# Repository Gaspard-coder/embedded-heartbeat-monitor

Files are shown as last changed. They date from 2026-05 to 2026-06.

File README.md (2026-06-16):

# This repository contains all of the necessary file to make a working heartbeat sensor
- Schematics
- PCB design files
- Embedded code running on MCUs

## Embedded software (`software/hsensor/`)

MicroPython application running on a Raspberry Pi Pico. It samples the
output of the TCRT5000 reflectance sensor (amplified by an op-amp), detects
heartbeats and displays the BPM together with the live waveform on the
0.96" ST7735 LCD.

### Files
- `ST7735.py` — driver for the 0.96" LCD (SPI, same wiring as the demo:
  DC=GP8, CS=GP9, SCK=GP10, MOSI=GP11, RST=GP12, BL=GP13).
- `main.py` — acquisition, heart rate detection and display loop.

### Wiring
- TCRT5000 + op-amp output → **pin 31 (GPIO26 / ADC0)** of the Pico.
- LCD: SPI1 on GP8–GP13 (see above).

### How the algorithm works

1. **Sampling.** `ADC(Pin(26))` is read every 10 ms (≈100 Hz), which is
   well above the highest expected heart-beat frequency (~3 Hz at 180 BPM)
   and matches the cutoff of the analog front-end.

2. **DC removal (high-pass filter).** The raw photoplethysmographic signal
   coming from the TCRT5000 is dominated by a large DC component (ambient
   reflectance of the skin) with a small pulsatile AC component on top. We
   subtract a slowly-tracking baseline computed as an exponential moving
   average:

   ```
   baseline ← (31 · baseline + raw) / 32
   x       ← raw − baseline
   ```

   With `α = 1/32` at 100 Hz, the equivalent cutoff is roughly 0.5 Hz —
   slow enough to leave the heartbeats untouched but fast enough to track
   drift in finger pressure or ambient light.

3. **Peak detection.** A heartbeat appears as a local maximum on the
   filtered signal `x`. For every new sample we check the *previous*
   sample: if it is greater than its two neighbours and above
   `PEAK_THRESHOLD`, it is declared a peak.

4. **Refractory period.** Once a peak has been detected, any new peak
   occurring within 300 ms is ignored. This caps the detected rate at
   200 BPM and avoids counting the dicrotic notch (the small secondary
   bump after each beat) as a separate heartbeat.

5. **BPM computation.** The time difference `dt` between two consecutive
   accepted peaks is pushed into a rolling buffer of the last 5
   intervals. The current heart rate is the average of that buffer:

   ```
   BPM = 60000 / mean(intervals_ms)
   ```

   Averaging over several beats smooths jitter due to noise and gives a
   stable reading on the display. If no peak is seen for more than 2 s
   (i.e. < 30 BPM, almost certainly a lost-contact event) the buffer is
   cleared and the BPM goes back to `--`.

6. **Display.** The LCD is refreshed every 200 ms — redrawing the full
   framebuffer is slow, so we deliberately do not refresh at the sampling
   rate. The top of the screen shows `BPM: XX`, and below it the last
   160 filtered samples are plotted (oldest on the left, newest on the
   right) with a blue zero-line.

### Tuning knobs (top of `main.py`)
- `PEAK_THRESHOLD` — minimum amplitude (in ADC LSB on the filtered signal)
  for a sample to qualify as a peak. Lower it if the analog gain is small,
  raise it if the signal is noisy.
- `BPM_WINDOW` — number of inter-beat intervals averaged.
- `REFRACTORY_MS` / `MAX_INTERVAL_MS` — accepted BPM range (currently
  30–200 BPM).
- `v // 30` in the plotting code — vertical scale of the waveform on the
  LCD.

### Running
Copy `ST7735.py` and `main.py` to the Pico (Thonny, `mpremote cp`, …).
`main.py` runs automatically at boot.

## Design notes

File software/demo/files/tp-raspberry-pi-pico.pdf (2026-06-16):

## Electronique pour les systèmes embarqués

# TP Raspberry PI pico

## 1 Introduction

Dans ce mini-TP, nous nous intéressons à la prise en main de la maquette Raspberry Pi Pico et plus particulièrement de son convertisseur analogique numérique (CAN). La Raspberry Pi Pico est une carte programmable construite autour du microcontrôleur RP2040. La carte intègre un ARM Cortex-M0+ Dual Core à 133 MHz. Elle dispose de 26 broches GPIO dont 3 entrées analogiques connectées à un CAN. La datasheet complète de la carte est disponible sur le lien suivant : https://datasheets.raspberrypi.com/pico/pico-datasheet.pdf.

Question 1.1 Parcourer la rapidement, notamment le chapitre 1 pour connaitre les principales fonctionnalités de la carte.

## 2 Programmation de la carte

La carte Raspberry Pi Pico se programme avec plusieurs langages. Nous vous invitons à utiliser dans le cadre de ce module le langage micropython qui permet de l’interactivité et une facilité d’utilisation. Vous pourrez bien évidemment si vous le souhaitez utiliser d’autres langages supportés par la carte notamment le C/C++. Dans la suite de ce mini-TP, nous utiliserons MicroPython https://www.raspberrypi.com/documentation/microcontrollers/micropython.html.

Pour programmer en MicroPython, il est nécessaire de l’installer sur la carte. Cette opération très simple décrite dans le lien ci-dessus, a été déjà réalisée sur les Raspberry Pi Pico utilisées dans ce TP. Une fois MicroPython installé, il est possible d’utiliser des environnements de développement comme Thonny https://thonny.org/ ou d’interagir avec la carte avec Pyboard.py. C’est un utilitaire qui permet d’interagir avec micropython à partir d’un interpréteur ou d’un code Python tournant sur le poste principal et permet notamment accéder au système de fichier de la carte pico. Nous utiliserons cette deuxième solution dans le cadre de ce mini-TP. Cependant l’utilisation de Thonny a également des intérêts en termes d’interactivité. N’hésitez pas à l’installer et l’utiliser pour le projet fil-rouge du module.
Sachez qu’il est possible d’avoir différents codes python sur la carte mais le code qui s’exécutera lors du démarrage est le code main.py qui bien évidemment peut faire appel à d’autres codes python sur la carte.
Pour tester la carte, nous allons, bien évidemment, faire clignoter une LED (une LED sous forme d’écran). What else !

from machine import Pin , Timer
led = Pin ( 25 , Pin . OUT )
timer = Timer ()

def blink ( timer ):
led . toggle ()

timer . init ( freq =2 .5 , mode = Timer . PERIODIC , callback = blink )

Charger le code sur la carte en utilisant la commande

./pyboard.py --device /dev/ttyACM0 blink.py

Il est également possible de rendre le code par défaut à l’aide de la commande

./pyboard.py --device /dev/ttyACM0 -f cp ./blink.py :main.py

Question 2.1 Changer la valeur de la fréquence dans blink.py et vérifier que la fonctionnalité de la carte.

## 3 Caractérisation du convertisseur

Nous allons à présent nous concentrer sur le CAN. La puce RP2040 contient un CAN à approximations successives, SAR en anglais. L’architecture du CAN ou ADC en anglais, est détaillé dans la datasheet de RP2040 https://datasheets.raspberrypi.com/rp2040/rp2040-datasheet.pdf#page=561. (https://datasheets.raspberrypi.com/rp2040/rp2040-datasheet.pdf#page=561)
Le CAN a une dynamique d’entrée allant de 0 à 3.3 V et a un fréquence d’opération maximale de 48 MHz. Nous allons le tester avec une fréquence d’échantillonnage de 1 kHz. On appliquera un signal d’entrée de fréquence 101 Hz, d’amplitude 1 Vpeak ou 2 Vpeak-to-peak et un offset de 1.65 V pour se centrer au milieu de la dynamique d’entrée.
Nous allons tester le CAN avec 2 approches différentes. La première qu’on appellera l’approche sleep est décrite par le code suivant :

from machine import Pin , ADC
import utime
adc = ADC ( Pin ( 26 , mode = Pin . IN ) )

while True :
start = utime . ticks_us () print ( adc . read_u16 () )

2

stop = utime . ticks_us ()
utime . sleep_us ( 1000 - stop + start )

La deuxième qu’on appellera l’approche interruption est décrite par le code suivant :

from machine import Timer , Pin , ADC

def interruption_handler ( pin ): print ( adc . read_u16 () )

if __name__ == " __main__ ":
adc = ADC ( Pin ( 26 , mode = Pin . IN ) )
soft_timer = Timer ( mode = Timer . PERIODIC , period =1 , callback = interruption_handler )

Charger le code sur la carte en utilisant la commande :

./pyboard.py --device /dev/ttyACM0 ADC_sleep.py ¹

Nous utiliserons Matlab pour faire l’acquisition des données envoyées sur le port série et pour faire le post traitement (tracé de la FFT et calcul du SNR). Configurer l’entrée sur le logiciel waveforms et connecter la à la GPIO 26 (pince rouge sur la GPIO , pince noir à la masse).

Question 3.1 Lancer le code script rasberryPIpico.m. Analyser le spectre. Quelle est la fréquence de la raie du signal ? Relever la valeur du SNDR.

Nous allons comparer à présent le résultat de l’acquisition à celle obtenue avec l’approche interruption Charger le code sur la carte en utilisant la commande

./pyboard.py --device /dev/ttyACM0 ADC_interrupt.py

Question 3.2 Lancer le code script rasberryPIpico.m. Analyser le spectre et relever la valeur du SNDR. Comparer les 2 approches.

## 4 Affichage sur l’écran

Le raspberry PI pico intègre un écran LCD. Le fichier ST7735.py contient la bibliothèque nécessaire pour piloter l’écran. Copier la bibliothèque sur la Raspberry en utilisant la commande suivante :

./pyboard.py --device /dev/ttyACM0 -f cp ./ST7735.py :

Le script LCDexample.py contient un exemple d’utilisation de l’écran. Charger le sur la carte en utilisant la commande

./pyboard.py --device /dev/ttyACM0 LCDexample.py

1. Vous pouvez arreter l’affichage sur le terminal en appuyant sur Ctrl+c

3

Modifier le pour qu’il fasse un affichage de votre choix. Par exemple, vous pouvez changer le texte affiché, les couleurs, dessiner des dents de scie, afficher la sortie du convertisseur en équivalent analogique, ...

## 5 Acquisition d’un signal cardiaque

Pour pouvoir avancer sur la conception de l’algorithme de calcul du rythme cardiaque parallèle de la conception de la carte d’acquisition du capteur, nous allons utiliser un signal cardiaque préenregistré. Sur Waveforms, commencer par désactiver l’entrée. Puis appuyer sur la molette à droite de type puis import to play → cardiac.txt. Fixer la fréquence ou le nombre d’échantillons par seconde à 90 Hz, l’amplitude à 1 V et l’offset à 1.65 V.

Question 5.1 Relancer le code ADC_interrupt.py pour relancer l’acquisition. Après avoir patienter une dizaine de secondes afin que la séquence se charge sur la carte Digilent, lancer le code script rasberryPIpico.m. Analyser la sortie temporellement et fréquentiellement.

Question 5.2 Proposer et implémenter un algorithme pour mesurer le rythme cardiaque. (Mais pour ça, vous avez jusqu’à fin juin).

4

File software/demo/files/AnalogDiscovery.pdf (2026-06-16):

# Analog Discovery 2

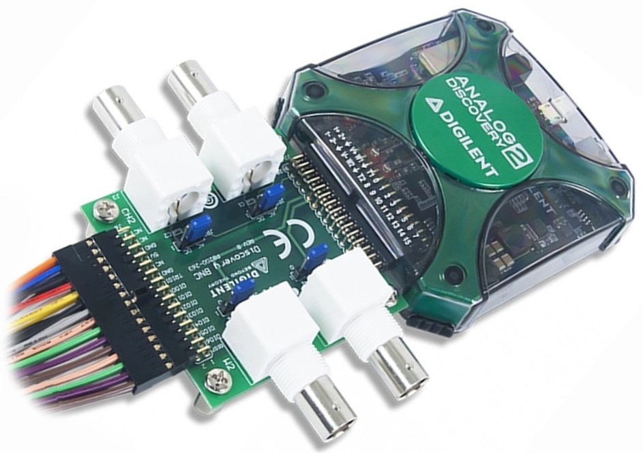
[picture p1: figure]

La carte Analog Discovery 2 est une carte d’instrumentation qui dispose de 2 voies de générations de signaux (notées W1 et W2 marqués par du vernis rose) et 2 voies d’acquisition (notées CH1 et CH2). Elle permet de remplacer (partiellement) le GBF et l’oscilloscope dans un banc de test classique. La carte utilise le logiciel Waveforms pour l’interfacege avec l’ordinateur.

Dans le cadre de ce TP, nous allons utiliser la carte en mode GBF.
Pour générer un sinusoide, il suffit d’aller sur Welcome → Wavegen. Ca ouvrira un menu qui vous permettra de configurer la sinusoide. Configurer les paramètres de votre sinusoide (fréquence, amplitude, offset, canal) puis appuyer sur Run.

Si vous souhaitez générer un signal audio, appuyez sur la molette à droite de Type → Import to Play. Chosisissez le fichier .wav que vous souhaitez importer, le logiciel détectera automatiquement les paramètres, il suffira ainsi d’appuyer sur OK. Configurer les autres paramètres (amplitude, offset) puis appuyez sur Run.

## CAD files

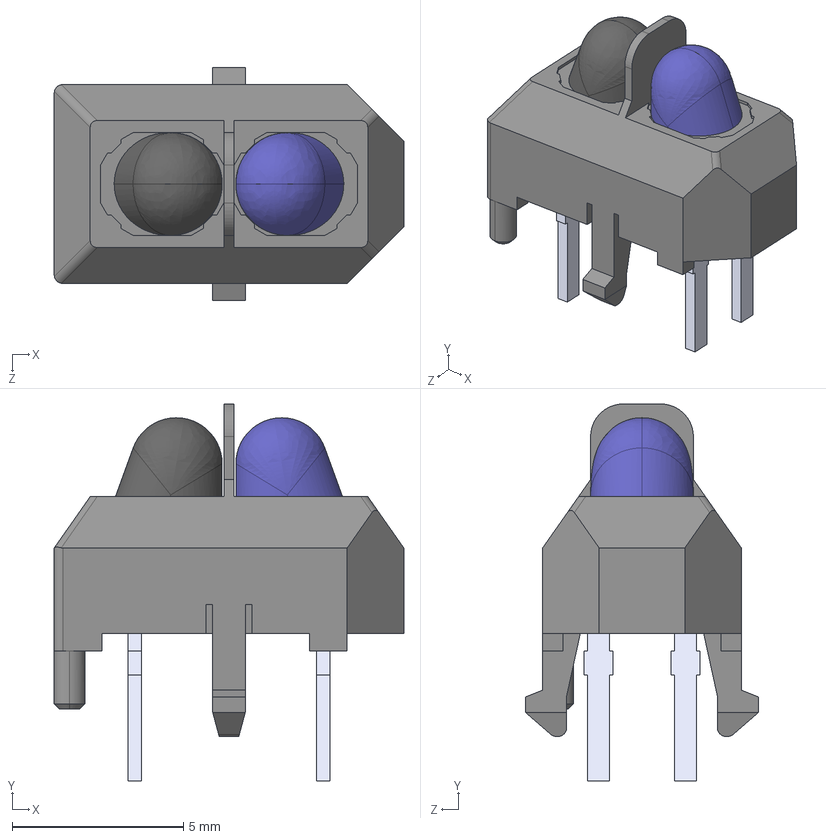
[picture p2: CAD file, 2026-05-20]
kicad projet/hsensor/TCRT5000.step
10.2 x 11.0 x 6.80 mm

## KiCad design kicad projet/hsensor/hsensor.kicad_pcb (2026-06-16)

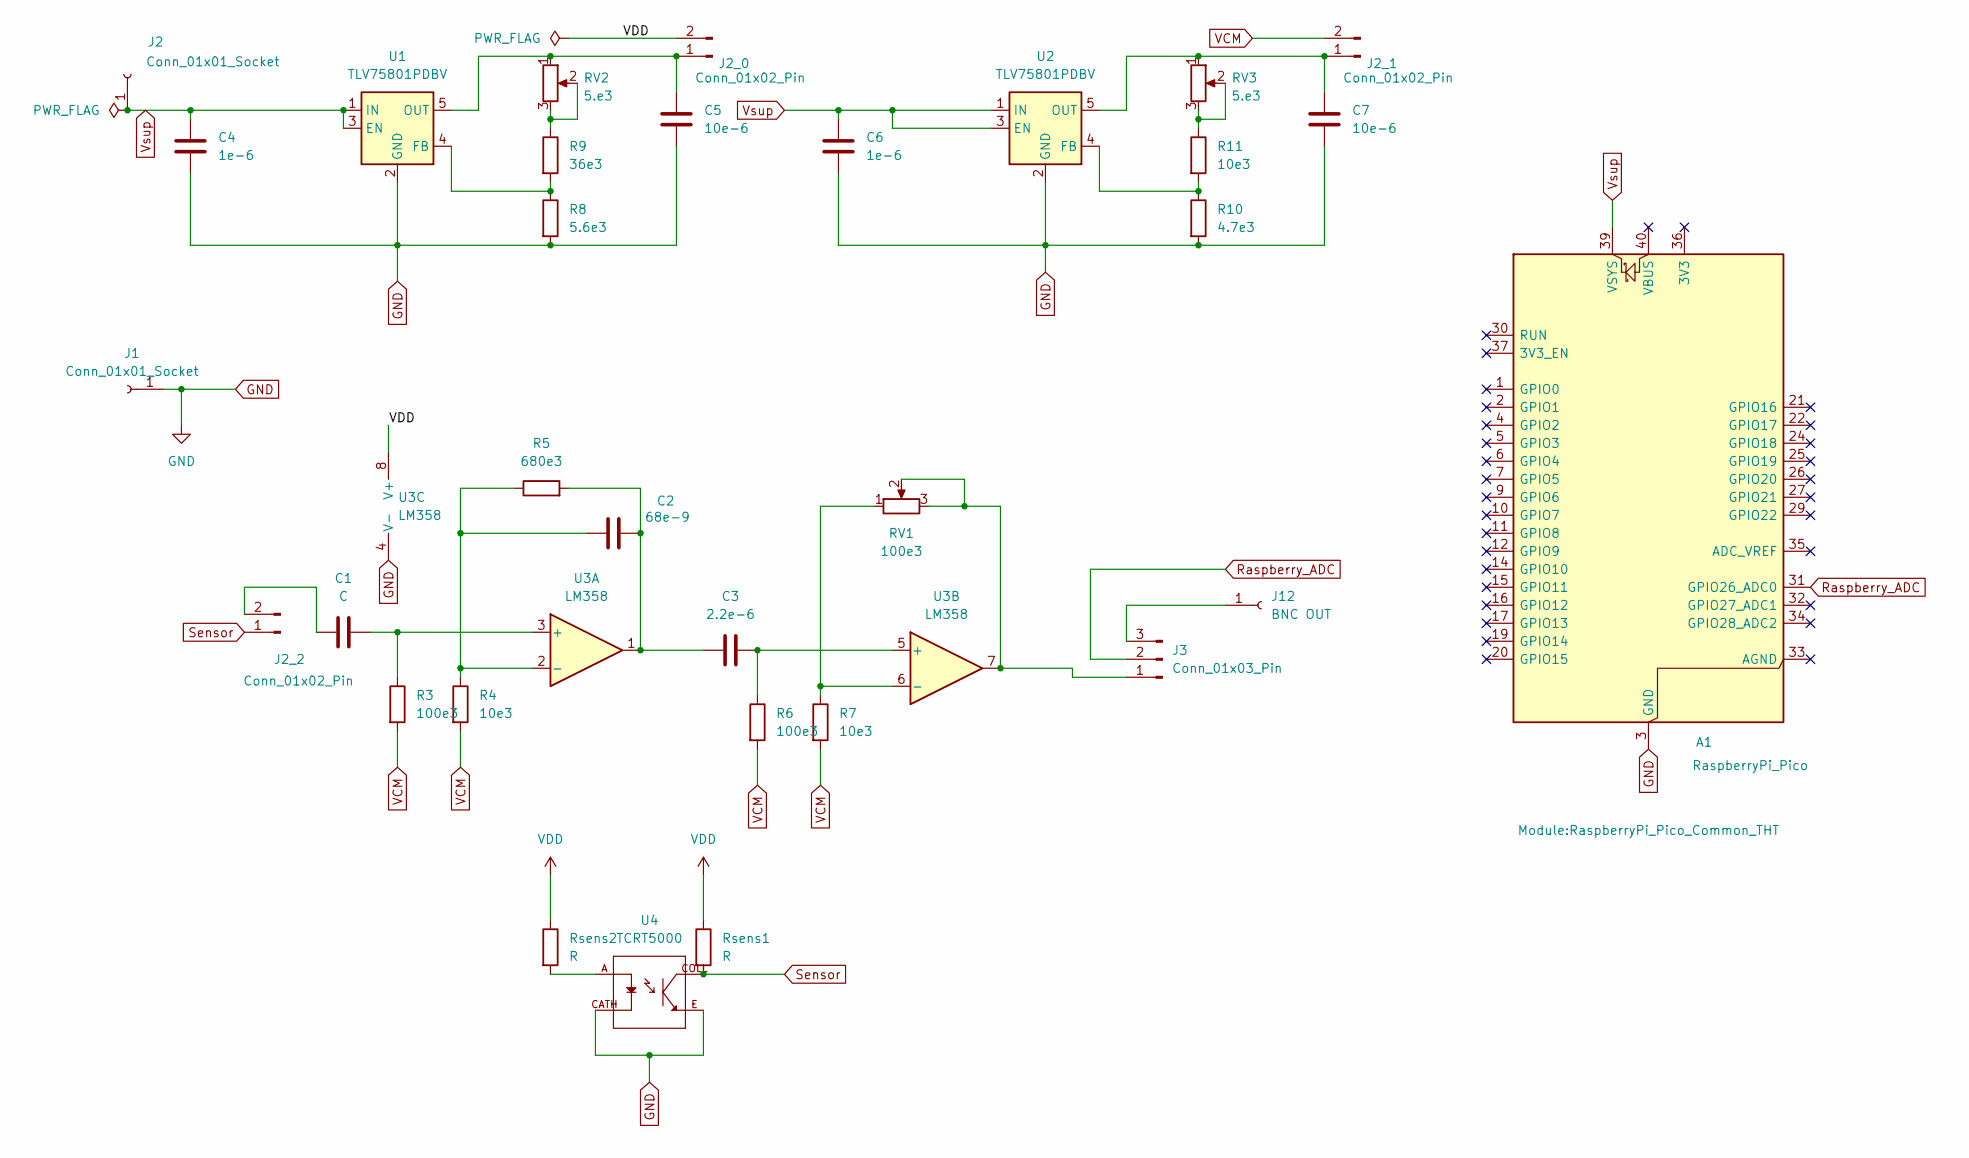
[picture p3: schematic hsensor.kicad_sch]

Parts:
A1: RaspberryPi_Pico; RaspberryPi_Pico_Common_THT
C1: C; C_1206_3216Metric
C2: 68e-9; C_1206_3216Metric
C3: 2.2e-6; C_1206_3216Metric
C4, C6: 1e-6; C_1206_3216Metric
C5, C7: 10e-6; C_1206_3216Metric
J1, J2: Conn_01x01_Socket
J2_0, J2_1, J2_2: Conn_01x02_Pin; PinHeader_1x02_P2.54mm_Vertical
J3: Conn_01x03_Pin; PinHeader_1x03_P2.54mm_Vertical
J12: BNC OUT
R3, R6: 100e3; R_1206_3216Metric
R4, R7, R11: 10e3; R_1206_3216Metric
R5: 680e3; R_1206_3216Metric
R8: 5.6e3; R_1206_3216Metric
R9: 36e3; R_1206_3216Metric
R10: 4.7e3; R_1206_3216Metric
RV1: 100e3; Potentiometer_Bourns_3266Y_Vertical
RV2, RV3: 5.e3; Potentiometer_Bourns_3266Y_Vertical
Rsens1, Rsens2: R; R_1206_3216Metric
U1, U2: TLV75801PDBV; SOT-23-5
U3: LM358; DIP-8_W7.62mm_Socket
U4: TCRT5000; OPTO_TCRT5000; PARTREV 1.7

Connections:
GND: A1.3 (GND), A1.8 (GND), A1.13 (GND), A1.18 (GND), A1.23 (GND), A1.28 (GND), A1.38 (GND), C4.1, C5.1, C6.1, C7.1, J1.1, R8.2, R10.2, U1.2 (GND), U2.2 (GND), U3.4 (V-), U4.CATH, U4.E
unnamed: C2.1, C3.2, R5.2, U3.1
unnamed: C5.2, J2_0.1, RV2.1, U1.5 (OUT)
unnamed: C7.2, J2_1.1, RV3.1, U2.5 (OUT)
unnamed: C1.2, J2_2.2
unnamed: J3.1, RV1.2, RV1.3, U3.7
unnamed: J3.3, J12.1
unnamed: R9.1, RV2.2, RV2.3
unnamed: R11.1, RV3.2, RV3.3
unnamed: Rsens2.2, U4.A
unnamed: R8.1, R9.2, U1.4 (FB)
unnamed: R10.1, R11.2, U2.4 (FB)
unnamed: C1.1, R3.1, U3.3 (+)
unnamed: C2.2, R4.1, R5.1, U3.2 (-)
unnamed: C3.1, R6.1, U3.5 (+)
unnamed: R7.1, RV1.1, U3.6 (-)
Raspberry_ADC: A1.31 (GPIO26_ADC0), J3.2
Sensor: J2_2.1, Rsens1.2, U4.COLL
VCM: J2_1.2, R3.2, R4.2, R6.2, R7.2
VDD: J2_0.2, Rsens1.1, Rsens2.1, U3.8 (V+)
Vsup: A1.39 (VSYS), C4.2, C6.2, J2.1, U1.1 (IN), U1.3 (EN), U2.1 (IN), U2.3 (EN)

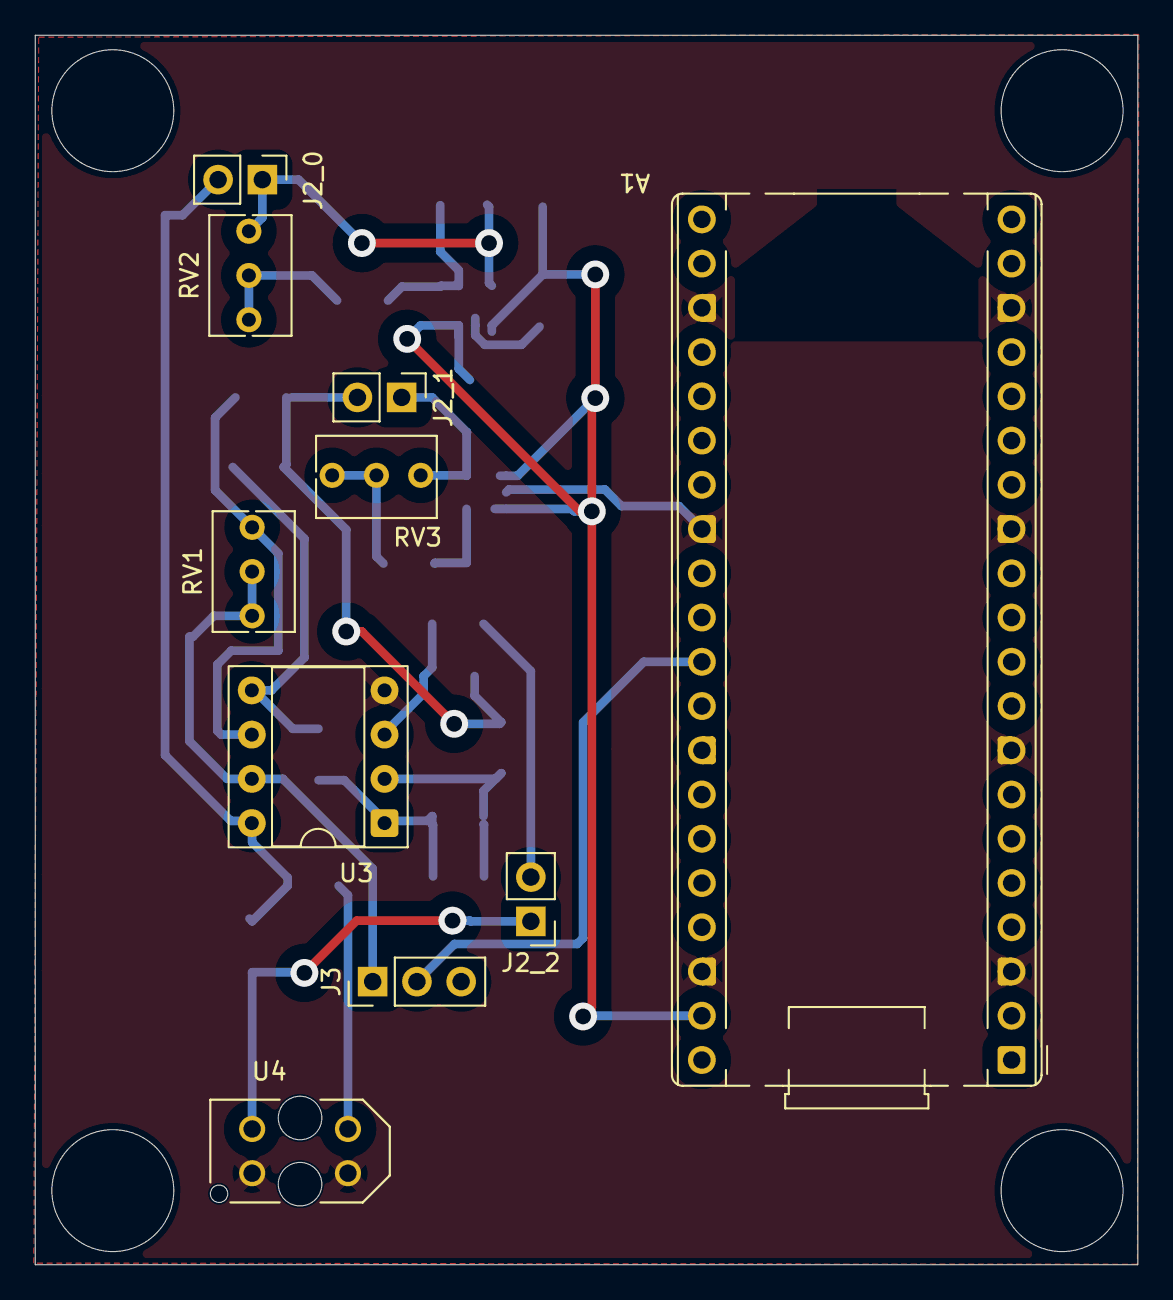
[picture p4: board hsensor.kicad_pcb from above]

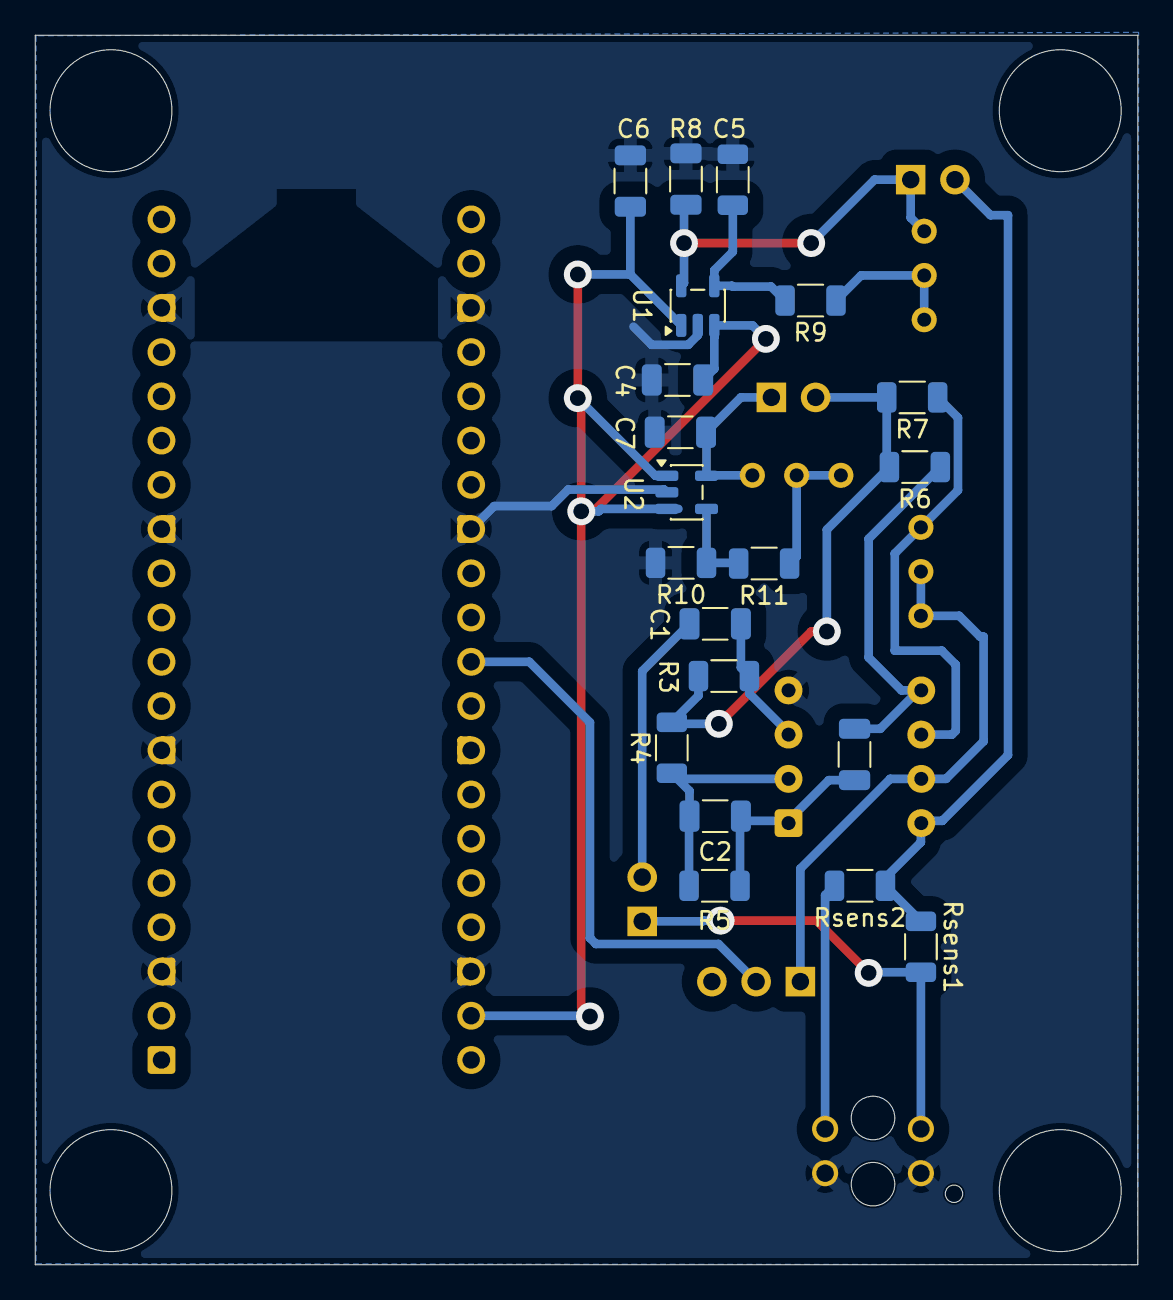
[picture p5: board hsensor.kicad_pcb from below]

Board: 2 copper layers, 63.3 x 70.6 mm, 30 parts (20 on the bottom side), 20 nets.

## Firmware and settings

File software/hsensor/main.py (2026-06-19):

from machine import Pin, SPI, PWM, Timer, ADC
from ST7735 import LCD_0inch96
import framebuf
import utime


# color is BGR
RED   = 0x00F8
GREEN = 0xE007
BLUE  = 0x1F00
WHITE = 0xFFFF
BLACK = 0x0000

# Sampling configuration
SAMPLE_PERIOD_US = 20000   # 10 ms -> 100 Hz sampling
SAMPLE_PERIOD_MS = 20
WAVEFORM_LEN = 160         # screen width in pixels
BPM_WINDOW = 10             # number of intervals averaged for BPM
PEAK_THRESHOLD = 3500       # AC amplitude (in u16 LSB) to qualify a peak
REFRACTORY_MS = 300        # min time between two peaks (-> max 200 BPM)
MAX_INTERVAL_MS = 2000     # -> min 30 BPM

# ADC on GPIO26 (physical pin 31)
adc = ADC(Pin(26, mode=Pin.IN))

# Initialize LCD
lcd = LCD_0inch96()
lcd.fill(BLACK)
lcd.text("Heart Rate", 40, 15, GREEN)
lcd.text("TCRT5000 PPG", 30, 35, BLUE)
lcd.text("Initializing...", 20, 55, WHITE)
lcd.display()
utime.sleep(1)

# Circular buffer of filtered samples for display
waveform = [0] * WAVEFORM_LEN
sample_idx = 0

# Peak detection state
baseline = adc.read_u16()   # running mean (DC component)
prev_x = 0
prev_prev_x = 0
last_peak_ms = 0
intervals = []
bpm = 0

last_display_ms = utime.ticks_ms()

while True:
    t0 = utime.ticks_us()

    # Acquire raw sample
    raw = adc.read_u16()
    t_ms = utime.ticks_ms()

    # High-pass filter: subtract a slowly tracking baseline
    # alpha = 1/32 -> cutoff ~ fs/(2*pi*32) ~= 0.5 Hz at 100 Hz sampling
    baseline = (baseline * 31 + raw) >> 5
    x = raw - baseline

    # Peak detection on the previous sample (local maximum above threshold)
    if (prev_x > PEAK_THRESHOLD) and (prev_x > prev_prev_x) and (prev_x > x):
        peak_time = t_ms - SAMPLE_PERIOD_MS
        if last_peak_ms != 0:
            dt = peak_time - last_peak_ms
            if (dt > REFRACTORY_MS) and (dt < MAX_INTERVAL_MS):
                intervals.append(dt)
                if len(intervals) > BPM_WINDOW:
                    intervals.pop(0)
                avg = sum(intervals) / len(intervals)
                bpm = int(60000 / avg)
                last_peak_ms = peak_time
            elif dt >= MAX_INTERVAL_MS:
                # gap too long -> restart from this peak
                last_peak_ms = peak_time
                intervals = []
                bpm = 0
        else:
            last_peak_ms = peak_time

    prev_prev_x = prev_x
    prev_x = x

    # Save filtered sample for display
    waveform[sample_idx] = x
    sample_idx = (sample_idx + 1) % WAVEFORM_LEN

    # Refresh display every 200 ms (don't redraw at full rate -> too slow)
    if utime.ticks_diff(t_ms, last_display_ms) > 200:
        lcd.fill(BLACK)
        if bpm > 0:
            lcd.text("BPM: " + str(bpm), 35, 5, RED)
        else:
            lcd.text("BPM: --", 45, 5, RED)

        # Plot the waveform centered around y=50, oldest sample on the left
        for i in range(WAVEFORM_LEN):
            idx = (sample_idx + i) % WAVEFORM_LEN
            v = waveform[idx]
            y = 50 - (v // 30)
            if y < 20:
                y = 20
            if y > 79:
                y = 79
            lcd.pixel(i, y, GREEN)

        # Baseline line
        lcd.hline(0, 50, WAVEFORM_LEN, BLUE)

        lcd.display()
        last_display_ms = t_ms

    # Keep the sample period constant
    elapsed = utime.ticks_diff(utime.ticks_us(), t0)
    sleep_us = SAMPLE_PERIOD_US - elapsed
    if sleep_us > 0:
        utime.sleep_us(sleep_us)

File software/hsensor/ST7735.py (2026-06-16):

from machine import Pin,SPI,PWM
import time
import framebuf

class LCD_0inch96(framebuf.FrameBuffer):
    def __init__(self):

        self.width = 160
        self.height = 80

        self.cs = Pin(9,Pin.OUT)
        self.rst = Pin(12,Pin.OUT)
#        self.bl = Pin(13,Pin.OUT)
        self.cs(1)
        # pwm = PWM(Pin(13))#BL
        # pwm.freq(1000)
        self.spi = SPI(1)
        self.spi = SPI(1,1000_000)
        self.spi = SPI(1,10000_000,polarity=0, phase=0,sck=Pin(10),mosi=Pin(11),miso=None)
        self.dc = Pin(8,Pin.OUT)
        self.dc(1)
        self.buffer = bytearray(self.height * self.width * 2)
        super().__init__(self.buffer, self.width, self.height, framebuf.RGB565)
        self.Init()
        self.SetWindows(0, 0, self.width-1, self.height-1)

    def reset(self):
        self.rst(1)
        time.sleep(0.2)
        self.rst(0)
        time.sleep(0.2)
        self.rst(1)
        time.sleep(0.2)

    def write_cmd(self, cmd):
        self.dc(0)
        self.cs(0)
        self.spi.write(bytearray([cmd]))

    def write_data(self, buf):
        self.dc(1)
        self.cs(0)
        self.spi.write(bytearray([buf]))
        self.cs(1)

    def backlight(self,value):#value:  min:0  max:1000
        pwm = PWM(Pin(13))#BL
        pwm.freq(1000)
        if value>=1000:
            value=1000
        data=int (value*65536/1000)
        pwm.duty_u16(data)

    def Init(self):
        self.reset()
        self.backlight(10000)

        self.write_cmd(0x11)
        time.sleep(0.12)
        self.write_cmd(0x21)
        self.write_cmd(0x21)

        self.write_cmd(0xB1)
        self.write_data(0x05)
        self.write_data(0x3A)
        self.write_data(0x3A)

        self.write_cmd(0xB2)
        self.write_data(0x05)
        self.write_data(0x3A)
        self.write_data(0x3A)

        self.write_cmd(0xB3)
        self.write_data(0x05)
        self.write_data(0x3A)
        self.write_data(0x3A)
        self.write_data(0x05)
        self.write_data(0x3A)
        self.write_data(0x3A)

        self.write_cmd(0xB4)
        self.write_data(0x03)

        self.write_cmd(0xC0)
        self.write_data(0x62)
        self.write_data(0x02)
        self.write_data(0x04)

        self.write_cmd(0xC1)
        self.write_data(0xC0)

        self.write_cmd(0xC2)
        self.write_data(0x0D)
        self.write_data(0x00)

        self.write_cmd(0xC3)
        self.write_data(0x8D)
        self.write_data(0x6A)

        self.write_cmd(0xC4)
        self.write_data(0x8D)
        self.write_data(0xEE)

        self.write_cmd(0xC5)
        self.write_data(0x0E)

        self.write_cmd(0xE0)
        self.write_data(0x10)
        self.write_data(0x0E)
        self.write_data(0x02)
        self.write_data(0x03)
        self.write_data(0x0E)
        self.write_data(0x07)
        self.write_data(0x02)
        self.write_data(0x07)
        self.write_data(0x0A)
        self.write_data(0x12)
        self.write_data(0x27)
        self.write_data(0x37)
        self.write_data(0x00)
        self.write_data(0x0D)
        self.write_data(0x0E)
        self.write_data(0x10)

        self.write_cmd(0xE1)
        self.write_data(0x10)
        self.write_data(0x0E)
        self.write_data(0x03)
        self.write_data(0x03)
        self.write_data(0x0F)
        self.write_data(0x06)
        self.write_data(0x02)
        self.write_data(0x08)
        self.write_data(0x0A)
        self.write_data(0x13)
        self.write_data(0x26)
        self.write_data(0x36)
        self.write_data(0x00)
        self.write_data(0x0D)
        self.write_data(0x0E)
        self.write_data(0x10)

        self.write_cmd(0x3A)
        self.write_data(0x05)

        self.write_cmd(0x36)
        self.write_data(0xA8)

        self.write_cmd(0x29)

    def SetWindows(self, Xstart, Ystart, Xend, Yend):#example max:0,0,159,79
        Xstart=Xstart+1
        Xend=Xend+1
        Ystart=Ystart+26
        Yend=Yend+26
        self.write_cmd(0x2A)
        self.write_data(0x00)
        self.write_data(Xstart)
        self.write_data(0x00)
        self.write_data(Xend)

        self.write_cmd(0x2B)
        self.write_data(0x00)
        self.write_data(Ystart)
        self.write_data(0x00)
        self.write_data(Yend)

        self.write_cmd(0x2C)

    def display(self):

        self.SetWindows(0,0,self.width-1,self.height-1)
        self.dc(1)
        self.cs(0)
        self.spi.write(self.buffer)
        self.cs(1)

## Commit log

2026-05-23 updated schematics
    [hsensor.kicad_pcb]
2026-05-25 final pcb (i hope)
    [hsensor.kicad_pcb, hsensor.kicad_sch]
2026-06-16 added demo files
    [hsensor.kicad_pcb]
